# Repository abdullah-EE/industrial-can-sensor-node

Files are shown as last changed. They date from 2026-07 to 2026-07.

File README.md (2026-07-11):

# Smart Brushed DC Motor Controller and Monitor

A staged electrical and embedded-systems portfolio project for industrial, robotics, electronics, power electronics, and hardware-test internships.

## Goal

Design and later build a low-voltage brushed DC motor controller that:

- controls a small 12 V brushed DC motor with PWM
- measures motor current and supply voltage
- monitors temperature and vibration
- detects stall, overcurrent, overheating, undervoltage, sensor failure, and CAN timeout
- shuts the motor down safely during critical faults
- communicates status and commands over CAN
- starts on a dev board and moves toward a custom PCB only after the basics are proven

## Current Version 1 Direction

Version 1 uses an STM32 Nucleo board, a discrete one-direction low-side MOSFET motor switch, shunt current sensing, divided supply-voltage sensing, basic temperature sensing, an accelerometer header, and a CAN transceiver.

This is intentionally not a BLDC, FOC, cloud, AI, dashboard, or high-power motor project.

## Repository Structure

- `docs/` - research notes, requirements, architecture, design decisions, and build plan
- `hardware/bom.csv` - first-pass bill of materials
- `hardware/ltspice/` - simulation starters
- `hardware/kicad/` - KiCad hardware notes
- `kicad/` - KiCad project files
- `firmware/` - STM32 firmware scaffold

## Validation Rule

Simulation results and measured results are separate. Anything in LTspice is design exploration until it is later checked on real hardware with a current-limited supply, meter, oscilloscope, and documented test procedure.

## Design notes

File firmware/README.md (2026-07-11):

# Firmware Scaffold

Target board for Version 1: `NUCLEO-G0B1RE`.

This scaffold separates project logic from STM32 HAL setup:

- `main.c` runs the simple application loop.
- `motor_control.*` clamps duty and forces safe shutdown.
- `adc_processing.*` converts raw ADC counts into engineering units.
- `fault_manager.*` owns fault detection and latching.
- `can_protocol.*` encodes and decodes a tiny command/status protocol.
- `platform.h` defines the hardware functions that the STM32Cube layer must provide later.
- `platform_stub.c` is a buildable placeholder for non-hardware review.

The next firmware task is to create an STM32CubeMX project for the NUCLEO-G0B1RE and implement `platform.h` using TIM PWM, ADC DMA or polling, FDCAN, GPIO, and watchdog setup.

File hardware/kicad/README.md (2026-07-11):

# KiCad Hardware Notes

The active KiCad project is in `kicad/`.

Version 1 schematic sections:

1. Input protection and motor supply
2. Low-side MOSFET motor switch
3. Shunt current sensing
4. 12 V supply voltage sensing
5. Temperature sensing
6. STM32 Nucleo interface
7. CAN transceiver and connector
8. Accelerometer header
9. Test points and debug labels

Important Version 1 net labels:

- `VIN_12V`
- `VMOTOR_12V`
- `MOTOR_SW`
- `MOTOR_CURRENT_SHUNT_HI`
- `MOTOR_CURRENT_SHUNT_LO`
- `ISENSE_ADC`
- `VSENSE_ADC`
- `TEMP_ADC`
- `PWM_GATE`
- `CAN_TX`
- `CAN_RX`
- `CANH`
- `CANL`
- `VDD_3V3`
- `VDD_5V`
- `PGND`
- `AGND`

Layout reminders for the future PCB:

- Keep the motor current loop short and wide.
- Place the flyback diode and bulk capacitor close to the motor connector and MOSFET loop.
- Use Kelvin-style sense routing from the shunt to the current-sense amplifier.
- Keep ADC filter parts close to the MCU input pins.
- Keep CANH/CANL routed as a pair and avoid long stubs.
- Add test points before layout gets crowded.

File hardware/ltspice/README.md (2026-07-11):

# LTspice Simulations

These files are starter simulations for Version 1 of the 12 V brushed DC motor controller.

Current files:

- `v1_low_side_motor_switch.cir` - low-side MOSFET motor switch with flyback diode and shunt resistor
- `v1_current_sense_filter.cir` - shunt plus current-sense gain and ADC RC filter
- `v1_voltage_divider_filter.cir` - 12 V rail divider and ADC RC filter

Rules:

- Do not treat simulated results as measured hardware performance.
- Replace generic device models with manufacturer models when the exact MOSFET, diode, and amplifier are selected.
- Record any plotted waveforms or measurements in a separate simulation note before comparing to hardware.

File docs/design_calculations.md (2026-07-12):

# Design Calculations

## Selected Motor

Motor: Pololu item 3039, 50:1 Micro Metal Gearmotor HPCB 12V.

Manufacturer data used:

- Rated voltage: 12 V
- No-load speed: 650 RPM
- No-load current: 80 mA
- Extrapolated stall torque: 0.67 kg.cm
- Extrapolated stall current: 0.75 A
- Manufacturer warning: stall values are theoretical and stalling can damage the motor/gearbox.
- Manufacturer operating guidance: keep brushed DC motor operation at 25 percent or less of stall current when possible.

Source: https://www.pololu.com/product/3039

Important interpretation: Pololu does not list a separate rated load current for item 3039. The design therefore uses the listed 80 mA no-load current, 0.75 A extrapolated stall current, and Pololu's 25 percent of stall-current guidance for the first continuous operating target.

## Motor Current Targets

Continuous learning target:

```text
I_cont_target = 0.25 * I_stall
I_cont_target = 0.25 * 0.75 A
I_cont_target = 0.1875 A
```

Firmware sustained-stall threshold:

```text
I_stall_detect = 0.60 A
I_stall_detect / I_stall = 0.60 A / 0.75 A = 80 percent
```

Firmware overcurrent shutdown threshold:

```text
I_shutdown = 0.90 A
I_shutdown / I_stall = 0.90 A / 0.75 A = 120 percent
```

Timing strategy:

```text
overcurrent debounce = 10 ms above 0.90 A
stall debounce = 150 ms above 0.60 A while PWM is commanded
```

Why this replaced the earlier 1.20 A shutdown threshold: the selected motor's stall current is only 0.75 A, and the manufacturer warns that stall operation can damage the motor or gearbox. A 1.20 A threshold is too high for a first bench build because it is 160 percent of the extrapolated stall current. Version 1 now uses 0.90 A as a short-duration critical threshold and 0.60 A as a sustained-stall threshold. First tests should still use a bench supply current limit around 0.5 A to 0.8 A until measured motor data exists.

## Motor Winding Approximation For Simulation

At stall, back-EMF is zero, so the winding resistance can be estimated from Ohm's law:

```text
R_motor = V_motor / I_stall
R_motor = 12 V / 0.75 A
R_motor = 16 ohm
```

LTspice uses `RMOTOR = 16` as a first approximation. Motor inductance is not specified by the motor product page, so `LMOTOR = 1 mH` remains an assumption for transient exploration only.

## MOSFET Selection

Selected MOSFET: Infineon IRLZ44NPBF.

Datasheet/library headline values used:

- N-channel logic-level MOSFET
- Drain-source voltage rating: 55 V
- TO-220 package
- Very large current margin compared with the 0.75 A motor stall current

Voltage margin:

```text
VDS_rating / V_motor = 55 V / 12 V = 4.58x
```

Conduction loss estimate using a conservative `RDS(on) = 0.035 ohm` at logic-level gate drive:

```text
P_Q_stall = I_stall^2 * RDS(on)
P_Q_stall = 0.75^2 * 0.035
P_Q_stall = 0.0197 W

P_Q_shutdown = I_shutdown^2 * RDS(on)
P_Q_shutdown = 0.90^2 * 0.035
P_Q_shutdown = 0.0284 W
```

Beginner meaning: the MOSFET should barely warm up in this Version 1 current range. The bigger risk is wiring/layout mistakes, not MOSFET heat.

## Gate Drive

Selected gate driver: Microchip TC4427ACPA.

Datasheet values used:

- Supply range: 4.5 V to 18 V
- Non-inverting dual MOSFET driver
- Logic high input threshold compatible with STM32 3.3 V output
- Peak output current: 1.5 A

Design choice:

- Power the TC4427A from the Nucleo 5 V rail.
- Drive its input from STM32 PWM.
- Add a 22 ohm series gate resistor.
- Add a 100 k gate pulldown so the MOSFET stays off during reset.
- Ground the unused driver input.

Approximate peak gate-resistor-limited current:

```text
I_gate_initial ~= V_driver / R_gate
I_gate_initial ~= 5 V / 22 ohm
I_gate_initial ~= 0.227 A
```

The driver can supply more than this, so the resistor mainly softens edges and reduces ringing.

## Flyback Diode

Selected diode: Diodes Incorporated 1N5822.

Manufacturer data used:

- Average rectified current: 3 A
- Repetitive reverse voltage: 40 V
- Schottky diode in DO-201AD package

Current margin:

```text
I_diode_rating / I_stall = 3 A / 0.75 A = 4x
```

Voltage margin:

```text
V_RRM / V_motor = 40 V / 12 V = 3.33x
```

The diode is connected from `MOTOR_SW` to `VMOTOR_12V`, with cathode at `VMOTOR_12V` and anode at `MOTOR_SW`.

## Shunt And Current Sense

Selected shunt: 0.05 ohm current-sense resistor.

Selected amplifier: INA180A1, gain 20 V/V.

Current-to-voltage equation:

```text
V_shunt = I_motor * R_shunt
V_isense = V_shunt * Gain
V_isense = I_motor * 0.05 ohm * 20
V_isense = I_motor * 1.0 V/A
```

At no-load current:

```text
V_isense = 0.08 A * 1.0 V/A = 0.08 V
ADC_counts = 0.08 / 3.3 * 4095 = 99 counts
```

At stall current:

```text
V_isense = 0.75 A * 1.0 V/A = 0.75 V
ADC_counts = 0.75 / 3.3 * 4095 = 931 counts
```

At firmware overcurrent shutdown current:

```text
V_isense = 0.90 A * 1.0 V/A = 0.90 V
ADC_counts = 0.90 / 3.3 * 4095 = 1117 counts
```

ADC full-scale current:

```text
I_full_scale = 3.3 V / 1.0 V/A = 3.3 A
```

Shunt power:

```text
P_shunt_stall = 0.75^2 * 0.05 = 0.028 W
P_shunt_shutdown = 0.90^2 * 0.05 = 0.041 W
P_shunt_3A = 3.0^2 * 0.05 = 0.45 W
```

A 1 W or 2 W 2512 shunt has comfortable margin.

## Supply Voltage Divider

Selected divider:

- Top resistor: 100 k
- Bottom resistor: 27 k
- ADC filter resistor: 1 k
- ADC filter capacitor: 47 nF

Divider ratio:

```text
Ratio = R_bottom / (R_top + R_bottom)
Ratio = 27000 / (100000 + 27000)
Ratio = 0.2126
```

ADC voltage at nominal supply:

```text
V_adc_12V = 12 V * 0.2126 = 2.55 V
ADC_counts_12V = 2.55 / 3.3 * 4095 = 3165 counts
```

ADC voltage at 15 V:

```text
V_adc_15V = 15 V * 0.2126 = 3.19 V
ADC_counts_15V = 3.19 / 3.3 * 4095 = 3958 counts
```

Approximate divider current at 12 V:

```text
I_divider = 12 V / 127 k = 94.5 uA
```

Divider resistor power:

```text
P_top = I^2 * 100 k = 0.000893 W
P_bottom = I^2 * 27 k = 0.000241 W
```

0805 resistors are more than sufficient.

ADC filter cutoff:

```text
f_c = 1 / (2*pi*R*C)
f_c = 1 / (2*pi*1000*47 nF)
f_c = 3386 Hz
```

This is fast enough for supply monitoring and slow enough to reduce PWM noise.

## PTC Fuse

Selected PTC: Littelfuse RXEF110.

Design intent:

- Hold current: 1.10 A
- Trip current: 2.20 A

Why this part:

- The selected motor has 0.75 A extrapolated stall current.
- The PTC should not trip instantly during normal startup or brief stall tests.
- Sustained wiring faults or incorrect larger motors should push it toward trip.

The PTC is not the only protection. Firmware overcurrent shutdown and bench supply current limiting are still required.

## TVS Diode

Selected TVS: Littelfuse SMBJ18A.

Design intent:

- 18 V reverse standoff is above normal 12 V operation.
- The 55 V MOSFET has margin above the TVS clamp region.
- The TVS is a protection footprint, not permission to hot-plug or abuse the board.

## Thermal Summary

At the selected motor's 0.75 A extrapolated stall current:

```text
P_shunt = 0.028 W
P_mosfet ~= 0.020 W
P_flyback is pulsed and depends on PWM duty and motor current decay
```

These losses are small. Thermal testing is still required because wiring, diode placement, board copper, and motor loading affect real temperatures.

## Final Version 1 Limits

- Nominal supply: 12 V
- Intended continuous motor current: about 0.19 A or less until measured
- Motor stall current from manufacturer: 0.75 A extrapolated
- Firmware overcurrent shutdown: 0.90 A for 10 ms
- Firmware sustained-stall threshold: 0.60 A for 150 ms while PWM is commanded
- ADC current full scale: about 3.3 A
- Bench supply current limit for first test: 0.5 A to 0.8 A

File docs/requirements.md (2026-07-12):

# Requirements

## Scope

Version 1 is a bench-tested 12 V brushed DC motor controller and condition-monitoring node.

## Functional Requirements

| ID | Requirement | Version 1 Target |
|---|---|---|
| F-001 | Motor control | One-direction PWM control of a small brushed DC motor |
| F-002 | PWM frequency | Start at 20 kHz unless switching losses or measurement noise require adjustment |
| F-003 | Motor voltage | Nominal 12 V DC |
| F-004 | Motor current | Selected motor is 80 mA no-load and 0.75 A extrapolated stall; Version 1 overcurrent target is 0.90 A for 10 ms and sustained-stall target is 0.60 A for 150 ms |
| F-005 | Current measurement | Low-side shunt and current-sense amplifier into STM32 ADC |
| F-006 | Supply measurement | Resistor divider and RC filter into STM32 ADC |
| F-007 | Temperature measurement | NTC or simple analog temperature sensor near MOSFET/motor connector |
| F-008 | Vibration interface | Header for a digital accelerometer module, initially LIS3DH-class I2C/SPI |
| F-009 | CAN communication | Receive command, transmit status, detect command timeout |
| F-010 | Safe shutdown | Force PWM duty to zero on critical faults |

## Fault Requirements

| ID | Fault | Version 1 Behavior |
|---|---|---|
| FAULT-001 | Overcurrent | Disable PWM if filtered current exceeds limit |
| FAULT-002 | Stall | Disable or limit PWM if high current persists while command is nonzero |
| FAULT-003 | Overtemperature | Disable PWM above configured temperature threshold |
| FAULT-004 | Undervoltage | Disable PWM below configured 12 V rail threshold |
| FAULT-005 | Sensor failure | Disable PWM if ADC reading is impossible or stuck out of range |
| FAULT-006 | CAN timeout | Disable PWM if no valid command arrives within timeout |

## Safety And Test Requirements

- First power-up must use a current-limited supply.
- First motor tests should begin with a low duty limit, such as 10 percent.
- The motor stage must include a flyback path.
- The motor supply must include bulk capacitance near the motor connector.
- Current shunt power must be checked before hardware testing.
- Test points are required for 12 V input, protected motor supply, gate drive, switch node, shunt sense, current-sense output, 3.3 V, CANH, CANL, and ground.
- Simulation results must be labeled as simulation only.
- Measured results must include test setup notes.

## Non-Goals For Version 1

- Bidirectional motor control
- BLDC control
- Field-oriented control
- Cloud connection
- Mobile or web dashboard
- Machine-learning fault detection
- High-power motor operation
- Automotive qualification
- Functional safety certification

## Open Uncertainties

- Measured stall current for the exact purchased Pololu 3039 motor.
- Real startup current waveform at the selected PWM frequency.
- Whether the first CAN transceiver will be a breakout module or on a small custom board.
- Exact accelerometer module choice.
- Final ADC sampling rate and filter constants after noise measurements.

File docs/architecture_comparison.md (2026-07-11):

# Architecture Comparison

## Version 1 Requirement

The first version must be simple, low-cost, understandable, and testable. It should target a 12 V brushed DC motor with roughly 1 A to 2 A maximum intended current and safe shutdown behavior. It does not need reverse direction, closed-loop speed control, BLDC control, FOC, cloud logging, or a dashboard.

## Option A: STM32 Nucleo Plus Discrete Low-Side MOSFET

Summary: Use a NUCLEO-G0B1RE for firmware, a low-side N-channel MOSFET to switch the motor, a flyback diode, a shunt resistor plus INA180 current-sense amplifier, a voltage divider for the 12 V rail, temperature sensing, an accelerometer header, and a CAN transceiver.

Advantages:

- Best learning value for power electronics basics.
- Easy to simulate in LTspice.
- Easy to probe with an oscilloscope.
- Keeps motor direction one-way, which reduces failure modes.
- Uses the Nucleo board for debug, power-up, and firmware bring-up.
- Maps naturally to a future custom PCB.

Disadvantages:

- Requires careful MOSFET, flyback, grounding, and shunt layout decisions.
- No reverse direction.
- Protection is partly firmware-based, so first testing must use a current-limited supply.

Decision: Recommended for Version 1.

## Option B: STM32 Nucleo Plus Integrated Brushed DC Driver

Summary: Use a brushed DC motor driver IC such as DRV8871, DRV8876, DRV8231A, or similar, with the STM32 providing PWM and fault logic.

Advantages:

- Built-in motor protection can reduce first-hardware risk.
- Fewer external power-stage components.
- Some parts include current regulation or current feedback.
- Good for later comparison against a discrete design.

Disadvantages:

- Less educational for MOSFET switching, flyback paths, and current-loop layout.
- Many driver ICs are H-bridges, which adds bidirectional capability before it is needed.
- Thermal-pad packages can be harder for a beginner to solder and inspect.

Decision: Rejected for Version 1, but kept as a backup if the discrete MOSFET stage becomes too difficult.

## Option C: Full H-Bridge With Discrete MOSFETs

Summary: Use four MOSFETs and a gate-driver strategy to control speed and direction.

Advantages:

- Supports forward and reverse.
- Looks closer to a complete motor controller product.
- Teaches high-side switching, dead time, and shoot-through prevention.

Disadvantages:

- Too much risk for Version 1.
- Requires more complex gate driving and layout.
- Shoot-through can destroy parts quickly.
- Harder to debug without strong test equipment habits.

Decision: Rejected for Version 1. Consider only after one-direction control is measured and documented.

## Option D: Custom STM32 PCB From The Start

Summary: Design the STM32, power supply, CAN, sensors, and motor stage all on one board immediately.

Advantages:

- Strong final portfolio artifact if successful.
- Forces complete schematic and PCB ownership.

Disadvantages:

- High bring-up risk.
- Firmware, MCU power, clocking, debug, motor switching, and CAN all fail together if the board has one mistake.
- Slows learning because every bug may be hardware, firmware, or assembly.

Decision: Rejected for Version 1. Use Nucleo first, then custom PCB later.

## Selected Version 1 Architecture

Use Option A:

NUCLEO-G0B1RE + one-direction low-side MOSFET motor stage + shunt current sensing + supply divider + temperature input + accelerometer header + 3.3 V CAN transceiver.

This is the simplest architecture that still demonstrates embedded systems, electronics, robotics, industrial hardware, power electronics, and hardware-test thinking.

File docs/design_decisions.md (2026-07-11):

# Design Decisions

## DD-001: Use STM32G0B1RE Nucleo For Version 1

Decision: Use NUCLEO-G0B1RE for first firmware and hardware bring-up.

Why:

- It includes an STM32 with FDCAN, ADC, timers, watchdogs, and enough flash/RAM.
- It provides SWD debug and USB without designing a custom MCU circuit first.
- It lowers risk while still using a real STM32 workflow.

Rejected alternatives:

- STM32F103 Blue Pill: cheap and popular, but board quality varies and CAN setup can be messy for beginners.
- Custom STM32 PCB first: impressive if it works, but too many bring-up risks at once.

## DD-002: Use One-Direction Low-Side MOSFET First

Decision: Version 1 controls motor speed in one direction only.

Why:

- It teaches MOSFET switching, flyback, shunt sensing, grounding, PWM, and fault shutdown.
- It avoids H-bridge shoot-through and high-side drive complexity.
- It matches the project rule to avoid unnecessary features.

Rejected alternatives:

- Integrated H-bridge: safer in some ways, but hides the power-stage learning.
- Discrete H-bridge: too much risk for Version 1.

## DD-003: Use Low-Side Shunt Current Sensing

Decision: Use a low-side shunt plus current-sense amplifier.

Why:

- It is simple to understand: current through a resistor creates a small voltage.
- It is easy to simulate.
- It is easy to probe.
- INA180-class devices are common and documented.

Tradeoff:

- The motor return is lifted slightly by the shunt voltage.
- Layout matters because noisy motor current and ADC ground must be handled carefully.

## DD-004: Put CAN In Version 1 But Keep Protocol Small

Decision: Include CAN hardware and a tiny command/status protocol.

Why:

- CAN is valuable for industrial and robotics internships.
- Timeout-to-safe-state is a meaningful embedded safety behavior.
- The protocol can stay small: command duty, enable bit, heartbeat, status, fault flags.

Rejected alternatives:

- USB-only control: easier but less aligned with industrial hardware.
- Cloud or dashboard: unnecessary and distracting.

## DD-005: Use External Or Module Power Rails During Bring-Up

Decision: During Version 1, power the Nucleo from USB and use a current-limited 12 V supply for the motor. Do not design the main buck converter yet.

Why:

- A switching regulator is a project by itself.
- Separating the logic supply from motor supply makes first tests safer.
- A custom PCB can add power conversion after the motor stage is proven.

## DD-006: Treat Vibration As An Interface First

Decision: Add a header for an accelerometer module before designing a custom MEMS sensor layout.

Why:

- It supports future condition monitoring.
- It avoids tiny LGA soldering in the first hardware step.
- It keeps Version 1 focused on motor control and fault handling.

## DD-007: Document Uncertainty

Decision: The design documents must mark assumptions and unknowns.

Why:

- Recruiters and engineers trust honest validation more than polished guesses.
- The motor stall current, thermal limits, ADC noise, and CAN timing should be measured later.

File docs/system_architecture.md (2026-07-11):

# System Architecture

## Version 1 Block Diagram

```text
12 V bench supply
    |
    |-- fuse or resettable fuse
    |-- reverse-polarity protection placeholder
    |-- TVS footprint placeholder
    |-- bulk capacitor
    |
    +--> motor +
          motor -
              |
              +--> low-side N-MOSFET drain
                       source --> shunt resistor --> power ground

STM32 NUCLEO-G0B1RE
    |
    |-- timer PWM --> gate driver or gate resistor --> MOSFET gate
    |-- ADC current input <-- INA180 output <-- shunt resistor
    |-- ADC voltage input <-- divider from protected 12 V
    |-- ADC temperature input <-- NTC or analog temperature sensor
    |-- I2C/SPI header --> vibration accelerometer module
    |-- FDCAN TX/RX --> 3.3 V CAN transceiver --> CANH/CANL connector
    |-- SWD/USB debug through Nucleo
```

## Power Domains

- `VIN_12V`: raw 12 V input from the current-limited bench supply.
- `VMOTOR_12V`: protected motor supply after fuse/protection.
- `VDD_5V`: optional 5 V rail from USB/Nucleo or module for the gate driver during early bring-up.
- `VDD_3V3`: STM32 logic and CAN transceiver supply from the Nucleo board during Version 1.
- `PGND`: high-current motor return.
- `AGND`: analog measurement reference. In Version 1 this joins ground at a planned point near the shunt/ADC reference path.

## Motor Power Stage

The first motor stage is a low-side switch:

- The motor connects between `VMOTOR_12V` and the MOSFET drain.
- The MOSFET source returns through the shunt resistor to ground.
- A flyback diode connects from the MOSFET drain/switch node back to `VMOTOR_12V`.
- A gate pulldown keeps the MOSFET off during reset.
- A series gate resistor reduces ringing and limits gate-drive current.

Beginner explanation: the STM32 cannot power the motor directly. The MOSFET acts like an electronically controlled switch. PWM turns the switch on and off quickly, and the motor averages that into a controllable speed.

## Sensing

Current:

- Use a low-side shunt so the first design is easy to understand.
- Start with 0.05 ohm and INA180A1 gain of 20 V/V.
- At 2 A, the shunt voltage is 0.1 V and the amplifier output is about 2.0 V.
- Shunt power at 2 A is I^2R = 0.2 W, so use a resistor with margin.

Voltage:

- Divide the 12 V rail to fit below the STM32 ADC limit.
- Example ratio: 100 k top and 27 k bottom gives about 2.55 V at 12 V and about 3.19 V at 15 V.
- Add an RC filter close to the MCU ADC pin.

Temperature:

- Start with an NTC divider or analog sensor placed near the MOSFET and motor connector.
- Use conservative firmware thresholds until measured thermal data exists.

Vibration:

- Add a header for an LIS3DH-class module.
- Do not claim condition-monitoring results until real vibration data is captured.

## CAN

- Use the STM32 FDCAN peripheral with a 3.3 V transceiver such as TCAN332.
- Add optional 120 ohm termination using a jumper or solder bridge.
- Keep the CAN stub short.
- Add test points for CANH and CANL.

## Safe State

The safe state is:

- PWM duty forced to 0 percent.
- MOSFET gate driven low or left pulled low.
- Fault latched in firmware until reset or explicit clear, depending on fault type.
- Status frame reports the fault code.

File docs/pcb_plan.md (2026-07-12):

# PCB Plan

## Scope

This is PCB preparation only. The board has a two-layer outline and logical component placement, but no traces are routed yet.

## Footprint And Pin Checks

Critical pin numbering was checked against manufacturer datasheets:

- IRLZ44NPBF: TO-220AB pin 1 gate, pin 2 drain, pin 3 source, tab drain. The schematic now maps Q1 pin 1 to `PWM_GATE`, pin 2 to `MOTOR_SW`, and pin 3 to `MOTOR_CURRENT_SHUNT_HI`.
- TC4427ACPA: PDIP-8 footprint. Pin 2 is IN A, pin 3 is GND, pin 4 is IN B, pin 5 is OUT B, pin 6 is VDD, pin 7 is OUT A. Unused input B is grounded.
- INA180A1IDBVR: SOT-23-5 DBV pinout A. Pin 1 OUT, pin 2 GND, pin 3 IN+, pin 4 IN-, pin 5 VS.
- TCAN332DR: SOIC-8. Pin 1 TXD, pin 2 GND, pin 3 VCC, pin 4 RXD, pin 5 NC, pin 6 CANL, pin 7 CANH, pin 8 NC.
- 1N5822: DO-201AD axial Schottky diode, cathode-band side connected to `VMOTOR_12V` for the flyback path.
- SMBJ18A: DO-214AA / SMB unidirectional TVS. Cathode side is planned on `VMOTOR_12V`, anode side on `PGND`.
- RXEF110: radial resettable PTC footprint added as a project footprint using the RXEF110 body and lead data.

Project-specific footprints were added for exact/selected parts not available as stock KiCad footprints:

- `Project_Footprints:Littelfuse_RXEF110`
- `Project_Footprints:OnShore_OSTVN02A150`
- `Project_Footprints:OnShore_OSTVN03A150`

## Board Outline And Placement

The board outline is a simple 120 mm x 80 mm two-layer rectangle.

Placement intent:

- 12 V input connector, PTC, TVS, and bulk capacitor sit together near the upper-left input area.
- Motor connector, flyback diode, MOSFET, and shunt are grouped in the left/middle motor-current area.
- TC4427 gate driver is close to the MOSFET gate resistor and gate pulldown.
- INA180 is close to the shunt, with the layout marked for Kelvin-style sense routing.
- TCAN332 is close to the CAN connector and CAN termination resistor.
- C4, C6, and C7 are local 100 nF decoupling capacitors near the TC4427, INA180, and TCAN332 supply pins.
- Test points are arranged along the lower board edge for easier probing.
- Four M3 mounting holes were placed near the corners.

## Ground And Current-Loop Strategy

The noisy current path is:

`VMOTOR_12V -> motor connector -> motor -> MOTOR_SW -> MOSFET drain/source -> shunt -> PGND -> input return`

During routing, this loop should be short and wide. The motor loop should stay on the left/motor side of the board. Analog signals and MCU/CAN logic should stay to the right where possible.

The shunt needs Kelvin-style sensing: the INA180 input traces should come from the shunt pads as separate thin sense traces, not from the wide motor-current copper after current has already spread through the board. This makes the current reading depend mostly on the shunt resistor voltage, not random copper voltage drops.

Use a bottom-layer ground pour later, but do not let high motor current force its way through the quiet analog/MCU area. The quiet sensing ground should return near the shunt/input-return area deliberately.

## Trace-Width Plan

No traces are routed yet. Planned starting widths:

- Motor and 12 V supply current paths: 1.0 mm minimum, preferably 1.5 mm to 2.0 mm where space allows.
- Shunt-to-MOSFET and motor flyback loop: short, wide copper with minimal loop area.
- Gate drive: about 0.25 mm to 0.40 mm is fine, kept short between TC4427, gate resistor, and MOSFET gate.
- ADC and INA180 sense traces: about 0.20 mm to 0.25 mm, routed as quiet Kelvin/signal traces away from the motor switch node.
- CANH/CANL: about 0.25 mm to 0.40 mm, routed together and kept away from the MOSFET switch node.

These are conservative beginner-friendly choices for a low-current 12 V board. Final widths should still be checked with the board house copper weight and temperature-rise assumptions before ordering.

## Current Check Results

KiCad checks run:

- Schematic ERC: `0 Errors, 0 Warnings`
- PCB DRC physical placement: `0 DRC violations`
- PCB unconnected items: `60`, expected because routing has not started
- Schematic parity warnings: `8`
  - 4 missing `PWR_FLAG` footprints, expected because schematic power flags are not physical PCB parts
  - 4 extra mounting-hole footprints, expected because mounting holes were intentionally added to the PCB

PCB routing has not started.

## Sources Used

- Infineon IRLZ44N datasheet
- Microchip TC4426A/TC4427A/TC4428A datasheet
- Texas Instruments INA180 datasheet
- Texas Instruments TCAN33x datasheet
- Diodes Incorporated 1N5822 datasheet
- Littelfuse SMBJ series datasheet
- Littelfuse RXEF series datasheet
- On Shore Technology OSTVNxxA150 drawing

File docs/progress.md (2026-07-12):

# Progress Log

## 2026-07-12

### Completed

- Inspected the repository and found an early 24 V industrial sensor-node skeleton with empty KiCad files and LTspice placeholders.
- Redirected the project to a 12 V smart brushed-DC motor controller and condition-monitoring node.
- Researched primary manufacturer and tool documentation for STM32G0B1RE, NUCLEO-G0B1RE, INA180 current sensing, brushed DC driver alternatives, CAN physical layer guidance, TCAN332, TC4427A, LIS3DH, KiCad, and LTspice.
- Reviewed common engineering-community patterns and beginner mistakes for motor-driver, PCB, and portfolio projects.
- Compared four Version 1 architectures.
- Selected the simplest strong Version 1 architecture: NUCLEO-G0B1RE plus one-direction low-side MOSFET motor stage, shunt current sensing, supply-voltage sensing, temperature sensing, accelerometer header, and CAN transceiver.
- Created:
  - `docs/research_notes.md`
  - `docs/architecture_comparison.md`
  - `docs/requirements.md`
  - `docs/system_architecture.md`
  - `docs/design_decisions.md`
  - `docs/build_plan.md`
  - `hardware/bom.csv`
- Began LTspice simulation files:
  - `hardware/ltspice/v1_low_side_motor_switch.cir`
  - `hardware/ltspice/v1_current_sense_filter.cir`
  - `hardware/ltspice/v1_voltage_divider_filter.cir`
- Began the KiCad schematic as a Version 1 schematic roadmap with named sections, nets, and required test points.
- Validated the KiCad schematic can be parsed/exported by KiCad 10 CLI.
- Created the firmware scaffold with modules for ADC conversion, CAN protocol, fault management, motor control, and platform abstraction.
- Updated `.gitignore` for KiCad history and local validation scratch files.

## 2026-07-12 Version 1 Electrical Selection Pass

### Completed

- Selected the Version 1 motor: Pololu item 3039, 50:1 Micro Metal Gearmotor HPCB 12V.
- Used manufacturer data for the motor selection:
  - 12 V rated voltage
  - 80 mA no-load current
  - 0.75 A extrapolated stall current
- Finalized exact critical parts in `hardware/bom.csv`:
  - Infineon IRLZ44NPBF MOSFET
  - Microchip TC4427ACPA MOSFET driver
  - Diodes Incorporated 1N5822 flyback diode
  - Bourns CSS2H-2512R-L500F 0.05 ohm shunt
  - Littelfuse RXEF110 resettable PTC
  - Littelfuse SMBJ18A TVS diode
  - Texas Instruments INA180A1IDBVR current-sense amplifier
  - Texas Instruments TCAN332DR CAN transceiver
- Added `docs/design_calculations.md` with current, voltage, power, thermal, ADC-scaling, divider, shunt, MOSFET, diode, fuse, and TVS calculations.
- Updated firmware current thresholds for the selected small motor:
  - sustained-stall detection current: 0.60 A for 150 ms
  - overcurrent shutdown: 0.90 A for 10 ms
- Updated LTspice motor model resistance to 16 ohm from the selected motor's 12 V / 0.75 A stall estimate.
- Replaced the KiCad text-only roadmap with a first real-symbol schematic pass using KiCad symbols for the MOSFET, diode, gate driver, INA180, TCAN332, connectors, protection, sensing, and passives.
- Confirmed the new KiCad schematic loads and exports a netlist.
- Ran KiCad ERC and saved the actual report to `hardware/kicad/erc_2026-07-12.rpt`.

### Blockers And Uncertainties

- LTspice was not installed on PATH or under the usual Program Files locations, so no actual LTspice plots or exported waveform data were generated.
- KiCad ERC is not clean. The current report has 63 errors and 102 warnings, mostly from dangling labels and off-grid hand-written wire endpoints.
- The KiCad schematic is a real-symbol first pass, but it still needs a KiCad GUI cleanup pass before it can be called electrically complete.
- Some exact footprints need verification or library mapping before PCB layout.
- The selected motor's stall current is manufacturer-extrapolated, not measured on the purchased motor.

### Blockers And Uncertainties

- Motor stall current must still be measured on the exact purchased motor before final lab validation.
- Temperature sensor conversion is a firmware placeholder until the exact NTC or analog sensor is selected.
- The KiCad schematic currently contains real symbols but is not ERC-clean.
- No local C compiler or CMake was available on PATH, so the firmware scaffold was not compiled in this environment.
- LTspice files were updated but not simulated here because LTspice was not installed.

## 2026-07-12 KiCad Repair Pass

### Completed

- Removed literal `??` unresolved-symbol markers from the schematic.
- Added a project-local symbol library at `kicad/v1_symbols.kicad_sym` and a project `sym-lib-table`.
- Verified the project-local symbol library loads by exporting SVGs with KiCad CLI.
- Verified `kicad/kicad.kicad_sch` exports a netlist with KiCad CLI.
- Reran KiCad ERC and saved the current report to `hardware/kicad/erc_2026-07-12-current.rpt`.
- Reviewed the old 1.20 A current shutdown threshold against the selected motor's 0.75 A extrapolated stall current.
- Changed firmware fault timing to:
  - overcurrent: 0.90 A for 10 ms
  - sustained stall: 0.60 A for 150 ms while PWM is commanded
- Located LTspice at `C:\Users\hayda\AppData\Local\Programs\ADI\LTspice\LTspice.exe`.
- Attempted LTspice batch runs for all three decks.

### Blockers And Uncertainties

- KiCad ERC is still not clean: current result is 43 violations, 4 errors, and 39 warnings.
- The 4 remaining ERC errors are input-protection symbol connection errors:
  - D2 pin 2 at `(60.96 mm, 30.48 mm)`
  - D2 pin 1 at `(60.96 mm, 40.64 mm)`
  - C1 pin 2 at `(78.74 mm, 30.48 mm)`
  - C1 pin 1 at `(78.74 mm, 40.64 mm)`
- Remaining ERC warnings are 4 footprint library warnings, 1 `PWM_GATE` label-multiple-wires warning, 1 isolated `TEMP_ADC` label warning, and 33 unconnected wire endpoint warnings.
- The schematic exports and has no `??` text, but the input-protection passives still need a KiCad GUI or standard-library-symbol cleanup before the schematic can be called electrically complete.
- LTspice batch commands returned exit code 0 but produced no `.raw`, `.log`, `.plt`, `.csv`, or exported waveform files. No simulation evidence exists yet.
- No PCB routing was started.

### Next Task

Fix KiCad schematic placement and ERC issues before routing:

- replace temporary project-local vertical passives with standard KiCad library symbols or valid corrected embedded symbols
- snap all symbols, wires, and labels to KiCad's connection grid
- fix all dangling labels and multiple-net-name warnings
- verify/import exact footprints for terminal blocks, PTC, thermistor, and test points
- rerun ERC until no genuine errors remain
- rerun LTspice interactively or fix the batch-output path, then save actual waveform data

## 2026-07-12 Schematic Cleanup Completion Pass

### Completed

- Replaced the temporary project-local symbols with embedded standard KiCad library symbols.
- Removed `kicad/sym-lib-table` and `kicad/v1_symbols.kicad_sym`; the schematic no longer depends on the temporary `V1:` library.
- Fixed the remaining D2/C1-style standard-symbol pin connection problems by using standard KiCad passives and correct pin coordinates.
- Fixed off-grid and dangling connection issues on:
  - 12 V input connector return
  - motor connector switch node
  - TC4427 input/output, power, ground, and unused channel
  - INA180 power and ground pins
  - TCAN332 TXD, RXD, VCC, GND, CANH, and CANL
  - CAN connector pins
- Reran KiCad ERC and saved the clean report to `hardware/kicad/erc_2026-07-12-current.rpt`.
- Current ERC result: `0 Errors, 0 Warnings`.
- Verified there are no unresolved `??` symbols and no `V1:` schematic symbols.
- Kept PCB routing unstarted.
- Ran LTspice 24.1.10 in batch ASCII mode and saved actual exported waveform evidence:
  - `hardware/ltspice/results/motor_switch_voltage_current_flyback.csv`
  - `hardware/ltspice/results/current_sense_output.csv`
  - `hardware/ltspice/results/supply_divider_output.csv`
- Updated `hardware/ltspice/results/README.md` with the simulated signals and LTspice log summaries.

### Remaining Warnings And Blockers

- KiCad ERC has no current warnings or errors.
- The ERC report still lists ignored check categories:
  - global label only appears once in the schematic
  - four connection points are joined together
  - SPICE model issue
  - assigned footprint does not match footprint filters
- Those ignored categories are KiCad check settings, not active violations in the current ERC report. They should be reviewed again before PCB layout.
- LTspice low-side switch log warns that the simple educational MOSFET model ignored `Cgdmax`, `Cgs`, and `Cds` parameters. The waveform data is still useful for first-order switching/current behavior, but it is not a validated MOSFET vendor model.
- The selected motor's 0.75 A stall current remains manufacturer-extrapolated and must be measured on the actual motor before final validation.
- PCB routing has not started.

### Next Task

Open the schematic in KiCad GUI for a visual review, then start footprint verification and PCB planning without routing until the schematic review is accepted.

## 2026-07-12 PCB Preparation Pass

### Completed

- Verified and corrected critical footprint/pin mapping before placement.
- Corrected Q1 so IRLZ44NPBF pin 1 is gate, pin 2 is drain to `MOTOR_SW`, and pin 3 is source to `MOTOR_CURRENT_SHUNT_HI`.
- Added local decoupling capacitors C6 and C7 for INA180 and TCAN332.
- Added project footprints for selected parts not covered exactly by stock KiCad footprints:
  - `Project_Footprints:Littelfuse_RXEF110`
  - `Project_Footprints:OnShore_OSTVN02A150`
  - `Project_Footprints:OnShore_OSTVN03A150`
- Updated `hardware/bom.csv` for the On Shore connector pitch and the actual decoupling capacitor references.
- Created a 120 mm x 80 mm two-layer PCB outline.
- Placed components by function:
  - input protection near power input
  - motor connector, flyback diode, MOSFET, and shunt close together
  - gate driver near MOSFET/gate resistor
  - INA180 near shunt
  - CAN transceiver near CAN connector
  - test points near the lower board edge
- Added four M3 mounting holes and simple silkscreen zone labels.
- Ran KiCad schematic ERC: `0 Errors, 0 Warnings`.
- Ran KiCad PCB DRC with schematic parity and saved `hardware/kicad/drc_2026-07-12-pcb-prep.rpt`.
- Confirmed the PCB has `0` routed tracks.
- Created `docs/pcb_plan.md`.

### Remaining Warnings And Blockers

- PCB routing has not started by request.
- PCB DRC reports `60` unconnected items because there are no routed traces yet.
- PCB DRC physical placement reports `0` violations.
- Schematic parity reports `8` expected footprint warnings:
  - 4 missing PWR_FLAG footprints because power flags are schematic-only
  - 4 extra mounting-hole footprints because mounting holes are PCB-only mechanical parts
- Before routing, visually review the board in KiCad and confirm the project-specific terminal block and PTC footprints against the actual purchased parts or printed 1:1 paper fit.

### Next Task

Perform a visual KiCad PCB review, then route only after confirming footprint fit and placement.

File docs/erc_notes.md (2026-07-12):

# ERC Notes

## 2026-07-12 KiCad ERC

Command run:

```powershell
& 'C:\Program Files\KiCad\10.0\bin\kicad-cli.exe' sch erc --output .tmp_erc.rpt kicad\kicad.kicad_sch
```

Saved report:

- `hardware/kicad/erc_2026-07-12-current.rpt`

Result:

- ERC completed.
- KiCad reported 43 total violations: 4 errors and 39 warnings.
- The schematic exports a netlist.
- No literal `??` unresolved-symbol markers remain in `kicad/kicad.kicad_sch`.
- The project-local symbol library `kicad/v1_symbols.kicad_sym` loads with `kicad-cli sym export svg`.

Remaining errors:

- D2 pin 2 at `(60.96 mm, 30.48 mm)` is reported unconnected.
- D2 pin 1 at `(60.96 mm, 40.64 mm)` is reported unconnected.
- C1 pin 2 at `(78.74 mm, 30.48 mm)` is reported unconnected.
- C1 pin 1 at `(78.74 mm, 40.64 mm)` is reported unconnected.

Interpretation:

- These are genuine schematic cleanup blockers in the input-protection area.
- The wires and junctions were placed at the reported coordinates, but KiCad still reports the custom vertical TVS/capacitor pins as unconnected. The next pass should replace these temporary project-local vertical symbols with standard KiCad library symbols or redraw the embedded pin geometry in the KiCad GUI.

Remaining warnings:

- 4 footprint library warnings for terminal-block/fuse symbols.
- 1 label-multiple-wires warning on `PWM_GATE`.
- 1 isolated label warning on `TEMP_ADC`.
- 33 unconnected wire endpoint warnings from the current hand-authored schematic geometry.

Next KiCad task:

Open the schematic in KiCad GUI, replace the temporary project-local passives with standard library symbols where possible, snap the remaining wires and labels to pins, verify the power and motor-current paths visually, then rerun ERC until there are zero genuine electrical errors.

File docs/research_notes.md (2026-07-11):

# Research Notes

## Project Framing

The project was redirected from a generic industrial CAN sensor node into a smart brushed-DC motor controller and condition-monitoring node. That is a stronger portfolio direction because it combines embedded firmware, power switching, sensing, protection, CAN communication, PCB design, and test planning in one buildable system.

The Version 1 design should prove the core behavior first:

- PWM control of a small 12 V brushed DC motor
- motor current measurement
- 12 V supply measurement
- simple temperature measurement
- vibration sensor interface
- CAN communication
- safe shutdown on faults

## Primary Technical Sources Reviewed

- STMicroelectronics STM32G0B1RE product page: the STM32G0B1 family includes a 64 MHz Arm Cortex-M0+ core, up to 512 KB flash, 144 KB SRAM, ADC, timers, comparators, watchdogs, and two FDCAN peripherals. This makes it a practical student MCU for PWM, ADC sampling, fault logic, and CAN without moving to a complex motor-control MCU. Source: https://www.st.com/en/microcontrollers-microprocessors/stm32g0b1re.html
- STMicroelectronics NUCLEO-G0B1RE page: the Nucleo-64 board exposes Arduino and ST morpho headers and includes the STM32G0B1RE MCU. This is useful for first bring-up because it provides SWD debug and USB without requiring a custom MCU board on day one. Source: https://www.st.com/en/evaluation-tools/nucleo-g0b1re.html
- TI INA180 product page and datasheet summary: the INA180 is a low-cost current-sense amplifier that can operate from 2.7 V to 5.5 V, has fixed gain options, and supports low-side current sensing. This fits a simple shunt measurement design. Source: https://www.ti.com/product/INA180
- TI DRV8871 product page and documentation list: integrated brushed DC motor drivers include current regulation and protection, but they hide some of the power-stage learning. The DRV8871 is still a useful rejected-option reference for current ratings, protection, and board-layout practices. Source: https://www.ti.com/product/DRV8871
- TI CAN physical-layer application report SLLA270: CAN uses a multipoint bus with twisted pair, termination at both ends, and attention to stub length and propagation delay. This supports using a real CAN transceiver, a 120 ohm termination option, short stubs, and test points. Source: https://www.ti.com/lit/an/slla270/slla270.pdf
- TI TCAN332 product page: a 3.3 V CAN transceiver is attractive because it avoids a 5 V logic interface between the STM32 and transceiver. Source: https://www.ti.com/product/TCAN332
- Microchip TC4427A product page: a simple dual MOSFET gate driver can drive a MOSFET gate harder than an STM32 pin and is easier to reason about than a full H-bridge driver. Source: https://www.microchip.com/en-us/product/TC4427A
- ST LIS3DH product page: a simple 3-axis digital accelerometer with I2C/SPI output is a reasonable later vibration sensor. For Version 1, a header for an accelerometer module is enough. Source: https://www.st.com/en/mems-and-sensors/lis3dh.html
- KiCad schematic documentation: KiCad supports labels, net classes, ERC, and forward annotation from schematic to PCB. This supports keeping schematic sections readable and assigning power nets intentionally. Source: https://docs.kicad.org/9.0/en/eeschema/eeschema.html
- Analog Devices LTspice page: LTspice is appropriate for early transient checks of the motor switch, flyback path, RC filters, and voltage divider behavior. Source: https://www.analog.com/en/resources/design-tools-and-calculators/ltspice-simulator.html

## Engineering Community Patterns Reviewed

Across manufacturer forums, KiCad discussions, PCB review discussions, and student project advice, recurring advice was:

- Make the first hardware revision small enough to finish and test.
- Show documentation, requirements, schematics, PCB decisions, firmware structure, and measured results.
- Do not pretend a simulation is a lab result.
- Add test points early.
- Separate noisy motor current loops from MCU analog measurements.
- Use a current-limited bench supply for first power-up.
- Use known-good dev boards and breakout modules before designing every subsystem from scratch.
- Recruiters tend to value projects that show tradeoffs, debugging evidence, and validation more than projects with many untested features.

## Common Beginner Mistakes To Avoid

- Choosing a motor whose stall current is far above the power stage rating.
- Reading only MOSFET threshold voltage and assuming the MOSFET is fully on.
- Forgetting a flyback path for an inductive motor.
- Routing motor current through the same thin ground path used by ADC measurements.
- Measuring current without considering shunt power dissipation.
- Adding bidirectional control before one-direction control is reliable.
- Designing a custom switching regulator before the main motor-control behavior is proven.
- Adding CAN before defining timeout and safe-state behavior.
- Presenting simulated waveforms as measured hardware data.

## Version 1 Research Conclusion

The best first version is a one-direction, low-side MOSFET motor controller using an STM32 Nucleo board and simple sensors. It gives strong internship value because it includes real power switching, embedded control, ADC sensing, fault handling, CAN, schematic capture, simulation, and eventual PCB layout, while staying buildable for a first-year student.

## Version 1 Part Selection Update

The motor was narrowed to Pololu item 3039, a 50:1 Micro Metal Gearmotor HPCB 12V. The important manufacturer data points are 12 V rated voltage, 80 mA no-load current, and 0.75 A extrapolated stall current. Pololu also warns that stall values are theoretical and that stalling can damage the motor or gearbox. Source: https://www.pololu.com/product/3039

The larger DFRobot 12 V encoder gearmotor class was not selected for Version 1 because published product data shows stall currents in the several-amp range. That would force a higher-current first build and move the project away from the requested low-cost, simple 1 A to 2 A bench target.

Final Version 1 critical parts selected from manufacturer documentation:

- Infineon IRLZ44NPBF MOSFET
- Microchip TC4427ACPA MOSFET driver
- Diodes Incorporated 1N5822 Schottky flyback diode
- Texas Instruments INA180A1IDBVR current-sense amplifier
- Texas Instruments TCAN332DR CAN transceiver
- Littelfuse RXEF110 resettable PTC
- Littelfuse SMBJ18A TVS diode

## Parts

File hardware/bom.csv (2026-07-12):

Category | Qty | Reference | Manufacturer | Manufacturer Part Number | Value_or_Rating | Package_or_Module | Status | Notes | Source
Development | 1 | U_DEV1 | STMicroelectronics | NUCLEO-G0B1RE | STM32G0B1RE Nucleo-64 board | Dev board | Selected | First bring-up MCU board with SWD/debug and FDCAN-capable MCU | https://www.st.com/en/evaluation-tools/nucleo-g0b1re.html
Motor | 1 | M1 | Pololu | 3039 | 50:1 Micro Metal Gearmotor HPCB 12V; 80 mA no-load; 0.75 A extrapolated stall | 10x12 mm micro gearmotor | Selected | Small safe bench motor; no encoder for Version 1 | https://www.pololu.com/product/3039
Power switch | 1 | Q1 | Infineon | IRLZ44NPBF | 55 V N-channel logic-level MOSFET | TO-220-3 | Selected | Overkill current rating but beginner-friendly and easy to solder/probe | https://www.infineon.com/part/IRLZ44N
Gate drive | 1 | U_GATE1 | Microchip | TC4427ACPA | 1.5 A dual non-inverting MOSFET driver | PDIP-8 | Selected | 5 V gate drive from Nucleo 5 V rail; unused input grounded | https://www.microchip.com/en-us/product/TC4427A
Flyback | 1 | D1 | Diodes Incorporated | 1N5822 | 3 A 40 V Schottky rectifier | DO-201AD | Selected | Flyback diode across motor for low-side switching | https://www.diodes.com/part/view/1N5822
Current sense | 1 | R_SHUNT1 | Bourns | CSS2H-2512R-L500F | 0.05 ohm 1 percent current sense resistor | 2512 | Selected | 0.028 W at 0.75 A stall; about 0.041 W at 0.90 A firmware shutdown
Current sense | 1 | U_ISENSE1 | Texas Instruments | INA180A1IDBVR | Gain 20 V/V current-sense amplifier | SOT-23-5 | Selected | 0.05 ohm shunt gives 1 V/A into ADC | https://www.ti.com/product/INA180
Voltage sense | 1 | R_VTOP1 | Yageo | RC0805FR-07100KL | 100 k 1 percent | 0805 | Selected | 12 V divider top resistor
Voltage sense | 1 | R_VBOT1 | Yageo | RC0805FR-0727KL | 27 k 1 percent | 0805 | Selected | 12 V divider bottom resistor
Filtering | 2 | C_ADC1 C_ADC2 | KYOCERA AVX | 08055C473KAT2A | 47 nF 50 V X7R | 0805 | Selected | ADC low-pass filter capacitors
Temperature | 1 | R_NTC1 | EPCOS / TDK | B57540G0103F000 | 10 k NTC thermistor | Through-hole bead | Selected | Simple board/motor-area temperature input
CAN | 1 | U_CAN1 | Texas Instruments | TCAN332DR | 3.3 V CAN transceiver | SOIC-8 | Selected | Matches STM32 3.3 V logic and keeps CAN simple | https://www.ti.com/product/TCAN332
CAN | 1 | R_TERM1 | Yageo | RC0805FR-07120RL | 120 ohm 1 percent | 0805 | Selected | Optional CAN bus termination via jumper
CAN | 1 | J_CAN1 | On Shore Technology | OSTVN03A150 | CANH CANL GND terminal block | 2.54 mm 3-position | Selected | Simple screw terminal for bench CAN wiring
Connector | 2 | J_POWER J_MOTOR | On Shore Technology | OSTVN02A150 | 2-position terminal block | 2.54 mm 2-position | Selected | 12 V input and motor output screw terminals
Input protection | 1 | F1 | Littelfuse | RXEF110 | Resettable PTC; 1.10 A hold; 2.20 A trip | Radial PTC | Selected | Allows normal and short stall testing but trips on sustained faults
Input protection | 1 | D_TVS1 | Littelfuse | SMBJ18A | 600 W unidirectional TVS; 18 V standoff | SMB/DO-214AA | Selected | Clamps supply transients below MOSFET voltage margin | https://www.littelfuse.com/products/overvoltage-protection/tvs-diodes/surface-mount/smbj/smbj18a
Power | 1 | C_BULK1 | Panasonic | EEU-FR1E471 | 470 uF 25 V low-ESR electrolytic | Radial | Selected | Near motor supply connector
Power | 3 | C4 C6 C7 | KYOCERA AVX | 08055C104KAT2A | 100 nF 50 V X7R | 0805 | Selected | Local driver current-sense and CAN decoupling
Vibration | 1 | J_ACC1 | Sullins | PPTC041LFBN-RC | Accelerometer module header 3.3 V I2C/SPI | 0.1 in 1x4 header | Selected | Header only; LIS3DH-class module later
Debug | 1 | J_NUCLEO1 | Sullins | PPTC101LFBN-RC | Nucleo signal header interface | 0.1 in 1x10 header | Selected | Breaks out PWM ADC CAN and supplies
Test | 13 | TP* | Keystone | 5000 | Loop test point | THT loop | Selected | VIN VMOTOR gate switch shunt ADC CAN and ground test points

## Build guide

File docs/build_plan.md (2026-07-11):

# Build Plan

## Stage 0: Repository Baseline

- Create requirements, architecture, research notes, decision log, build plan, progress log, and BOM.
- Begin LTspice simulations.
- Begin KiCad schematic structure.
- Begin firmware scaffold.

## Stage 1: Bench Prototype Without Motor

- Wire Nucleo, gate driver input, MOSFET gate pulldown, and dummy LED/load.
- Generate PWM at low duty.
- Confirm safe-state disables PWM.
- Confirm ADC channels return sane values using known voltages.

Exit criteria:

- PWM pin toggles at expected frequency.
- Duty command is limited by firmware.
- Fault manager can force duty to zero.

## Stage 2: Current-Limited Motor Test

- Use a small 12 V brushed DC motor.
- Set bench supply current limit below the planned maximum at first.
- Start with low duty limit.
- Probe gate, switch node, shunt voltage, current-sense output, and supply rail.

Exit criteria:

- Motor spins in one direction.
- Current reading is plausible compared with bench supply reading.
- Flyback behavior does not exceed component voltage ratings in measured scope captures.

## Stage 3: Fault Handling

- Test overcurrent threshold with a controlled load condition.
- Test undervoltage by lowering supply voltage.
- Test CAN timeout by stopping command frames.
- Test sensor fault behavior using disconnected or forced ADC inputs.

Exit criteria:

- Every critical fault disables PWM.
- Fault code is reported.
- The test log separates expected behavior from measured behavior.

## Stage 4: CAN Bring-Up

- Connect CAN transceiver and USB-CAN adapter or second node.
- Send command frames.
- Receive status frames.
- Confirm command timeout behavior.

Exit criteria:

- Valid command updates duty setpoint.
- Invalid or missing command leads to safe state.

## Stage 5: Custom PCB Preparation

- Convert prototype circuit into a complete KiCad schematic.
- Review current-loop layout.
- Add test points and connector labels.
- Add optional termination and protection footprints.
- Run ERC and DRC.

Exit criteria:

- Schematic reviewed.
- PCB review checklist completed.
- Fabrication is delayed until simulation and bench prototype issues are resolved.

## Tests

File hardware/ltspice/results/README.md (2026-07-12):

# LTspice Results

## 2026-07-12

LTspice executable used:

- `C:\Users\hayda\AppData\Local\Programs\ADI\LTspice\LTspice.exe`

Command pattern used from `hardware/ltspice`:

```powershell
& 'C:\Users\hayda\AppData\Local\Programs\ADI\LTspice\LTspice.exe' -b -ascii <deck>.cir
```

Actual exported waveform evidence:

- `motor_switch_voltage_current_flyback.csv`
  - source deck: `../v1_low_side_motor_switch.cir`
  - exported columns: `time`, `V(sw)`, `I(Rmotor)`, `I(Dfly)`
- `current_sense_output.csv`
  - source deck: `../v1_current_sense_filter.cir`
  - exported columns: `time`, `V(isense_adc)`, `V(isense_raw)`, `V(shunt_node)`
- `supply_divider_output.csv`
  - source deck: `../v1_voltage_divider_filter.cir`
  - exported columns: `time`, `V(vin_12v)`, `V(vsense_adc)`, `V(vsense_raw)`

Simulation summaries from LTspice logs:

- Low-side motor switch:
  - average motor current from 5 ms to 10 ms: `0.293581739608 A`
  - peak motor current from 0 ms to 10 ms: `0.355529999072 A`
  - peak switch-node voltage from 0 ms to 10 ms: `12.5527299537 V`
- Current-sense filter:
  - max `V(ISENSE_ADC)`: `2.5 V`
- Supply divider:
  - `V(VSENSE_ADC)` at 12 V input: `2.51527700834 V`
  - `V(VSENSE_ADC)` at 9 V input: `1.95537249829 V`
  - `V(VSENSE_ADC)` at 15 V input: `3.1765692121 V`

These are simulation results only. They are not measured hardware validation.

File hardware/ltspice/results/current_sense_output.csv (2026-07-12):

time | V(isense_adc) | V(isense_raw) | V(shunt_node)
0.000000000000000e+00 | 0.000000000000000e+00 | 0.000000000000000e+00 | 0.000000000000000e+00
4.999999719812465e-11 | 0.000000000000000e+00 | 0.000000000000000e+00 | 0.000000000000000e+00
9.999999439624929e-11 | 0.000000000000000e+00 | 0.000000000000000e+00 | 0.000000000000000e+00
1.999999887924986e-10 | 0.000000000000000e+00 | 0.000000000000000e+00 | 0.000000000000000e+00
3.999999775849972e-10 | 0.000000000000000e+00 | 0.000000000000000e+00 | 0.000000000000000e+00
7.999999551699943e-10 | 0.000000000000000e+00 | 0.000000000000000e+00 | 0.000000000000000e+00
1.599999910339989e-09 | 0.000000000000000e+00 | 0.000000000000000e+00 | 0.000000000000000e+00
3.199999820679977e-09 | 0.000000000000000e+00 | 0.000000000000000e+00 | 0.000000000000000e+00
6.399999641359955e-09 | 0.000000000000000e+00 | 0.000000000000000e+00 | 0.000000000000000e+00
1.279999928271991e-08 | 0.000000000000000e+00 | 0.000000000000000e+00 | 0.000000000000000e+00
2.559999856543982e-08 | 0.000000000000000e+00 | 0.000000000000000e+00 | 0.000000000000000e+00
5.119999713087964e-08 | 0.000000000000000e+00 | 0.000000000000000e+00 | 0.000000000000000e+00
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

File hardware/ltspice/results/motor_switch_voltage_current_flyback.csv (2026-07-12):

time | V(sw) | I(Rmotor) | I(Dfly)
0.000000000000000e+00 | 1.199999999963581e+01 | 2.276001609402556e-11 | 0.000000000000000e+00
9.999999960041972e-12 | 1.199999999963590e+01 | 2.486888472930104e-11 | 7.815970093361102e-13
1.999999992008394e-11 | 1.199999999963594e+01 | 2.486888472930104e-11 | 8.171241461241152e-13
3.999999984016789e-11 | 1.199999999963602e+01 | 2.486888472930104e-11 | 7.815970093361102e-13
7.999999968033578e-11 | 1.199999999963617e+01 | 2.486899575160351e-11 | 7.105427357601002e-13
1.599999993606716e-10 | 1.199999999963646e+01 | 2.486899575160351e-11 | 7.460698725481052e-13
3.199999987213431e-10 | 1.199999999963700e+01 | 2.486899575160351e-11 | 6.039613253960852e-13
6.399999974426862e-10 | 1.199999999963805e+01 | 2.486888472930104e-11 | 7.460698725481052e-13
1.279999994885372e-09 | 1.199999999964047e+01 | 2.486899575160351e-11 | 7.460698725481052e-13
2.559999989770745e-09 | 1.199999999964539e+01 | 2.486877370699858e-11 | 7.815970093361102e-13
5.119999979541490e-09 | 1.199999999965566e+01 | 2.486888472930104e-11 | 8.526512829121202e-13
1.023999995908298e-08 | 1.199999999967612e+01 | 2.486855166239366e-11 | 7.460698725481052e-13
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

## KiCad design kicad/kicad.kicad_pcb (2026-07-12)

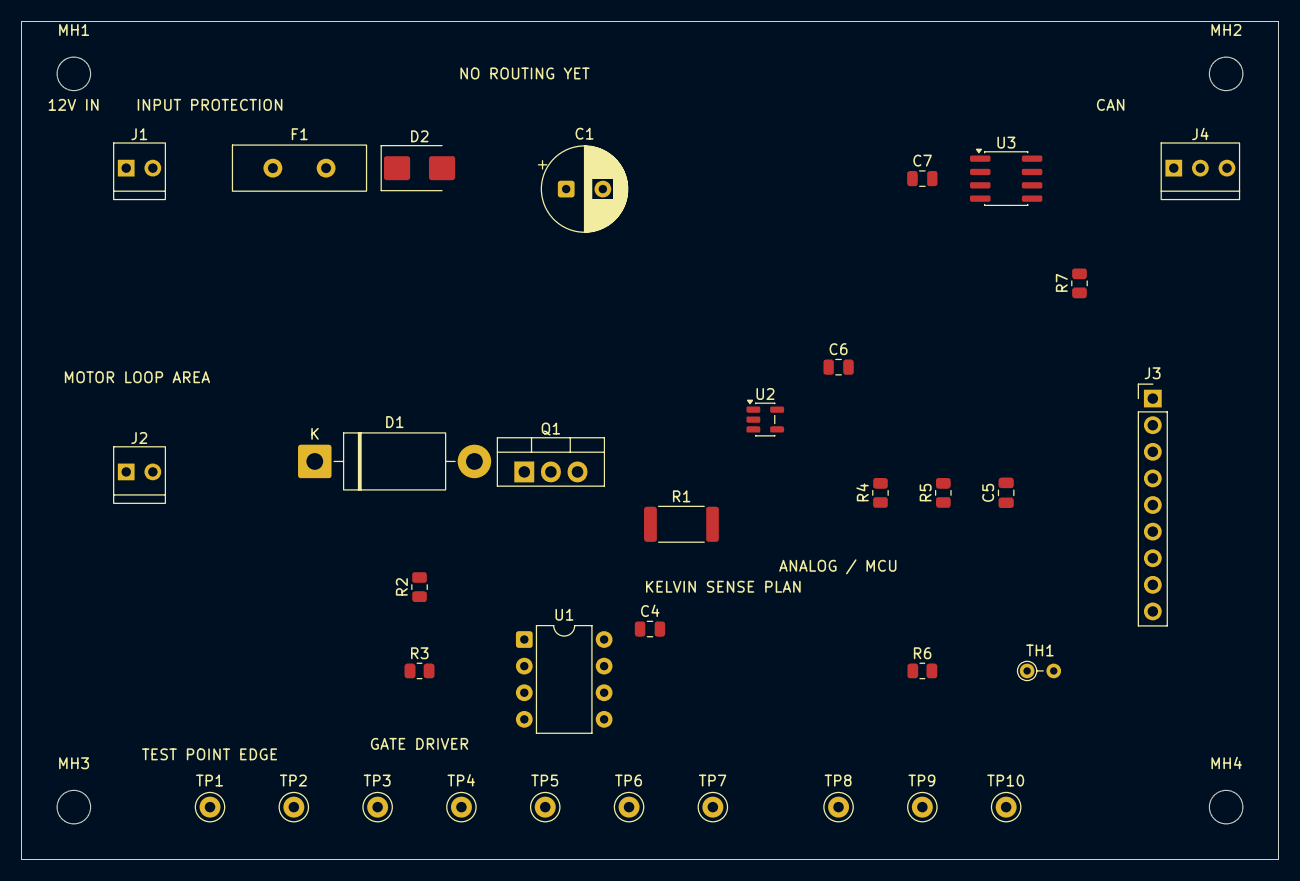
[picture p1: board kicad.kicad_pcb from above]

Board: 2 copper layers, 120.0 x 80.0 mm, 38 parts (0 on the bottom side), 17 nets, no tracks yet.

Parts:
C1: 470uF_25V; CP_Radial_D8.0mm_P3.50mm
C4: 100nF_DRIVER; C_0805_2012Metric
C5: 47nF_VSENSE; C_0805_2012Metric
C6: 100nF_INA180; C_0805_2012Metric
C7: 100nF_TCAN332; C_0805_2012Metric
D1: 1N5822_FLYBACK; D_DO-201AD_P15.24mm_Horizontal
D2: SMBJ18A; D_SMB
F1: RXEF110_PTC; Littelfuse_RXEF110
J1: 12V_INPUT; OnShore_OSTVN02A150
J2: MOTOR_OUT; OnShore_OSTVN02A150
J3: NUCLEO_HEADER; PinHeader_1x09_P2.54mm_Vertical
J4: CAN_BUS; OnShore_OSTVN03A150
MH1, MH2, MH3, MH4: M3; MountingHole_3.2mm_M3
Q1: IRLZ44NPBF; TO-220-3_Vertical
R1: 0.05R_SHUNT; R_2512_6332Metric
R2: 22R_GATE; R_0805_2012Metric
R3: 100k_GATE_PD; R_0805_2012Metric
R4: 100k_VSENSE_TOP; R_0805_2012Metric
R5: 27k_VSENSE_BOTTOM; R_0805_2012Metric
R6: 10k_TEMP_TOP; R_0805_2012Metric
R7: 120R_CAN_TERM; R_0805_2012Metric
TH1: 10k_NTC; R_Axial_DIN0204_L3.6mm_D1.6mm_P2.54mm_Vertical
TP1: VMOTOR_12V; TestPoint_Keystone_5000-5004_Miniature
TP2: MOTOR_SW; TestPoint_Keystone_5000-5004_Miniature
TP3: PWM_GATE; TestPoint_Keystone_5000-5004_Miniature
TP4: MOTOR_CURRENT_SHUNT_HI; TestPoint_Keystone_5000-5004_Miniature
TP5: ISENSE_ADC; TestPoint_Keystone_5000-5004_Miniature
TP6: VSENSE_ADC; TestPoint_Keystone_5000-5004_Miniature
TP7: TEMP_ADC; TestPoint_Keystone_5000-5004_Miniature
TP8: CANH; TestPoint_Keystone_5000-5004_Miniature
TP9: CANL; TestPoint_Keystone_5000-5004_Miniature
TP10: PGND; TestPoint_Keystone_5000-5004_Miniature
U1: TC4427ACPA; DIP-8_W7.62mm
U2: INA180A1IDBVR; SOT-23-5
U3: TCAN332DR; SOIC-8_3.9x4.9mm_P1.27mm

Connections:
/CANH: J4.1, R7.1, TP8.1, U3.7
/CANL: J4.3, R7.2, TP9.1, U3.6
/CAN_RX: J3.6, U3.4
/CAN_TX: J3.5, U3.1
/GATE_DRV_OUT: R2.1, U1.7
/ISENSE_ADC: J3.2, TP5.1, U2.1
/MOTOR_CURRENT_SHUNT_HI: Q1.3, R1.1, TP4.1, U2.4
/MOTOR_SW: D1.2, J2.2, Q1.2, TP2.1
/PGND: C1.2, C4.2, C5.2, C6.2, C7.2, D2.2, J1.2, J3.9, J4.2, R1.2, R3.2, R5.2, TH1.2, TP10.1, U1.3, U1.4, U2.2, U2.3, U3.2
/PWM_FROM_STM32: J3.1, U1.2
/PWM_GATE: Q1.1, R2.2, R3.1, TP3.1
/TEMP_ADC: J3.4, R6.2, TH1.1, TP7.1
/VDD_3V3: C6.1, C7.1, J3.7, R6.1, U2.5, U3.3
/VDD_5V: C4.1, J3.8, U1.6
/VIN_12V: F1.2, J1.1
/VMOTOR_12V: C1.1, D1.1, D2.1, F1.1, J2.1, R4.1, TP1.1
/VSENSE_ADC: C5.1, J3.3, R4.2, R5.1, TP6.1

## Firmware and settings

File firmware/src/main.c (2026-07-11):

#include "adc_processing.h"
#include "app_config.h"
#include "can_protocol.h"
#include "fault_manager.h"
#include "motor_control.h"
#include "platform.h"

int main(void)
{
    motor_control_t motor;
    fault_manager_t fault_manager;
    motor_command_t command = {0};
    uint32_t last_command_ms = 0u;
    uint32_t last_status_ms = 0u;

    platform_init();
    motor_control_init(&motor);
    fault_manager_init(&fault_manager);

    for (;;) {
        const uint32_t now_ms = platform_millis();
        can_frame_t rx;

        while (platform_can_receive(&rx)) {
            if (can_protocol_decode_command(&rx, &command)) {
                motor_control_set_command(&motor, command.enable, command.duty_per_mille);
                last_command_ms = now_ms;
            }
        }

        const adc_raw_t raw = platform_adc_read_latest();
        const measurements_t measurements = adc_processing_convert(raw);
        const uint32_t can_age_ms = now_ms - last_command_ms;

        const fault_flags_t faults = fault_manager_update(&fault_manager,
                                                          &measurements,
                                                          motor.requested_duty_per_mille,
                                                          can_age_ms,
                                                          APP_CONTROL_PERIOD_MS);

        motor_control_apply(&motor, faults);
        platform_fault_led_set(faults != FAULT_NONE);

        if ((now_ms - last_status_ms) >= 100u) {
            const can_frame_t status = can_protocol_make_status(motor.applied_duty_per_mille,
                                                               measurements.motor_current_a_x1000,
                                                               measurements.supply_voltage_v_x1000,
                                                               faults);
            platform_can_send(&status);
            last_status_ms = now_ms;
        }

        platform_wait_for_next_tick();
    }
}

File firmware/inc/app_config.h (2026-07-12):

#ifndef APP_CONFIG_H
#define APP_CONFIG_H

#include <stdint.h>

#define APP_PWM_FREQUENCY_HZ          20000u
#define APP_CONTROL_PERIOD_MS         1u
#define APP_CAN_TIMEOUT_MS            100u

#define APP_DUTY_STARTUP_LIMIT_PERMILLE 250u
#define APP_DUTY_MAX_PERMILLE           1000u

#define APP_OVERCURRENT_A_X1000       900
#define APP_OVERCURRENT_TIME_MS       10u
#define APP_STALL_CURRENT_A_X1000     600
#define APP_STALL_TIME_MS             150u
#define APP_UNDERVOLTAGE_V_X1000      9000
#define APP_OVERTEMP_C_X1000          80000

#define APP_ADC_COUNTS_FULL_SCALE     4095u
#define APP_ADC_REF_MV                3300u

#define APP_SHUNT_MILLIOHM            50u
#define APP_CURRENT_SENSE_GAIN        20u
#define APP_VDIV_TOP_OHM              100000u
#define APP_VDIV_BOTTOM_OHM           27000u

#define CAN_ID_MOTOR_COMMAND          0x100u
#define CAN_ID_MOTOR_STATUS           0x101u

#endif

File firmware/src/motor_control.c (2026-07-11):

#include "motor_control.h"
#include "app_config.h"
#include "platform.h"

static uint16_t clamp_duty(uint16_t duty, uint16_t limit)
{
    if (duty > limit) {
        return limit;
    }
    return duty;
}

void motor_control_init(motor_control_t *motor)
{
    motor->requested_duty_per_mille = 0u;
    motor->applied_duty_per_mille = 0u;
    motor->duty_limit_per_mille = APP_DUTY_STARTUP_LIMIT_PERMILLE;
    motor->enabled = 0u;
    platform_pwm_set_duty_per_mille(0u);
}

void motor_control_set_command(motor_control_t *motor, uint8_t enable, uint16_t duty_per_mille)
{
    motor->enabled = enable ? 1u : 0u;
    motor->requested_duty_per_mille = clamp_duty(duty_per_mille, APP_DUTY_MAX_PERMILLE);
}

void motor_control_apply(motor_control_t *motor, fault_flags_t faults)
{
    if (!motor->enabled || (faults != FAULT_NONE)) {
        motor->applied_duty_per_mille = 0u;
    } else {
        motor->applied_duty_per_mille =
            clamp_duty(motor->requested_duty_per_mille, motor->duty_limit_per_mille);
    }

    platform_pwm_set_duty_per_mille(motor->applied_duty_per_mille);
}

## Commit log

2026-07-11 Create KiCad workspace
2026-07-11 add these kicad tools
    [kicad.kicad_pcb, kicad.kicad_sch]
2026-07-11 Create brushed DC motor controller baseline
    [bom.csv, kicad.kicad_sch]
2026-07-11 Select version 1 motor electronics
    [bom.csv, kicad.kicad_sch]
2026-07-12 Repair KiCad schematic symbols and current limits
    [bom.csv, kicad.kicad_sch]
2026-07-12 Finish schematic ERC cleanup
    [current_sense_output.csv, kicad.kicad_sch, motor_switch_voltage_current_flyback.csv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]
2026-07-12 Prepare PCB placement without routing
    [bom.csv, kicad.kicad_pcb, kicad.kicad_sch]
